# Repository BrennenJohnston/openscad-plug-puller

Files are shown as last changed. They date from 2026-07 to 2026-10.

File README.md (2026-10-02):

# openscad-plug-puller






## Overview

The **Plug Puller** is a handheld assistive device that helps you grip and
remove an electrical plug from a wall outlet with your whole hand instead of
a fingertip pinch: two finger holes take the pull, and the tool touches only
the plug's sides and back, never the outlet. It is for anyone with
arthritis, low grip strength, tremor, a small hand or one hand. It is a
parametric OpenSCAD model: measure a few things with a ruler (or match your
plug against a printed stencil card), type them into a form, export, print.

It comes as **two tools**, each in its own file:

- the **one-sided puller**,
  [`src/Plug_Puller_Parametric.scad`](src/Plug_Puller_Parametric.scad):
  a slab with a plug pocket, finger holes, a cord hook, and zip-tie /
  velcro attachment, for lamp plugs, standard 3-prong plugs and other
  plugs thinner than 24 mm;
- the **two-sided puller**,
  [`src/Plug_Puller_Two_Sided.scad`](src/Plug_Puller_Two_Sided.scad):
  two identical serrated plates that zip-tie face to face around a
  thick round plug, a USB-C tip or a charger plug.

Not sure which? Start with the one-sided puller. If your plug measures
24 mm thick or more, it shows a red tag:
`PLUG THICKER THAN 24MM - USE THE TWO-SIDED PULLER FILE`.

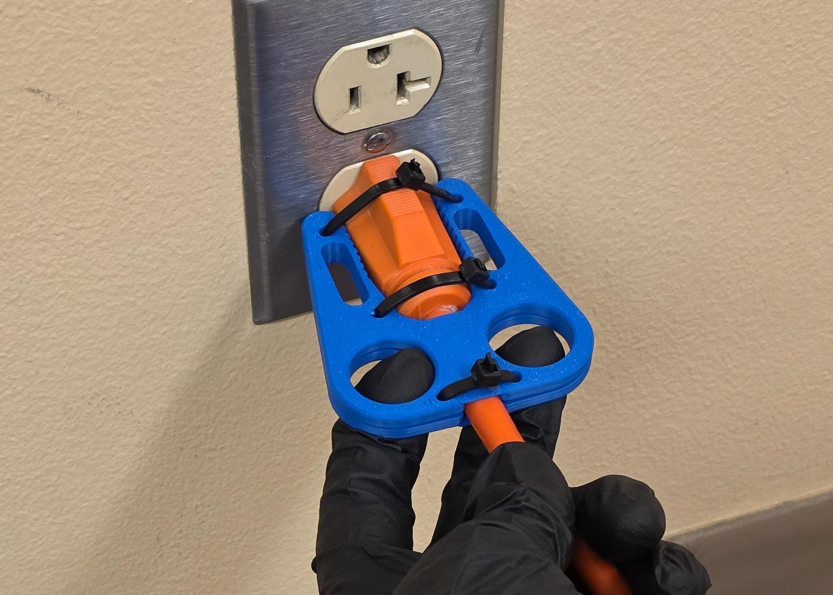
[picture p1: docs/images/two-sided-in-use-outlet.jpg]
A gloved hand pulling the two-sided puller and its orange extension-cord plug straight out of a wall outlet, two fingers through the holes.


> **Public preview** — one step from the **v1.0** public milestone. The
> geometry and guides are complete and print-tested, the shipped STLs
> are CI-validated against golden fixtures, and the model is
> customizable in the browser with nothing to install.

Each tool has two documents, as a page and as a printable PDF: a **quick
start** (get the file, measure, the four Customizer steps, print, assemble,
use) and a **full guide** (every dial, troubleshooting, the advanced dials).
One-sided puller: [quick start](docs/guides/one-sided/quick-start.md) and
[full guide](docs/guides/one-sided/full-guide.md). Two-sided puller:
[quick start](docs/guides/two-sided/quick-start.md) and
[full guide](docs/guides/two-sided/full-guide.md).

## How to obtain the device

### Customize in your browser

No install needed: the [OpenSCAD Assistive Forge](https://openscad-assistive-forge.pages.dev/),
our browser version of OpenSCAD built for keyboard and screen reader
use, opens the tool from one link, ready to customize, and offers to
keep a copy in your browser:
**[open the one-sided puller](https://openscad-assistive-forge.pages.dev/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)**
or
**[open the two-sided puller](https://openscad-assistive-forge.pages.dev/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)**.
The form shows the four steps' dials first. Each tool's quick start
covers it click by click under "Get the file", and its full guide adds
the notes for working in the browser. The links open the flattened
single-file builds, [`dist/Plug_Puller_SingleFile.scad`](dist/Plug_Puller_SingleFile.scad)
and [`dist/Plug_Puller_Two_Sided_SingleFile.scad`](dist/Plug_Puller_Two_Sided_SingleFile.scad),
as copied to the Forge's example branch.

### Customize on your computer

You don't need to know OpenSCAD (or any 3D modeling) to make a Plug
Puller that fits **your** plug and **your** hand.

1. Open the file for your tool in OpenSCAD (v2021.01 or later; recent
   builds with the Manifold backend render fastest):
   [`src/Plug_Puller_Parametric.scad`](src/Plug_Puller_Parametric.scad)
   for the one-sided puller, or
   [`src/Plug_Puller_Two_Sided.scad`](src/Plug_Puller_Two_Sided.scad)
   for the two-sided puller.
2. Open the **Customizer** panel (`View ▸ Hide Customizer` unchecked;
   older builds: `Window ▸ Customizer`).

   **One-sided puller:**
   - **Step 1 - Your Plug**: pick a `plug_preset` (or leave it on
     `Measure my plug` and type your plug measurements — see the
     [quick start](docs/guides/one-sided/quick-start.md)). Skip both to
     get the reference plug pocket. The preview shows a see-through
     plug built from your numbers. The measurements are named for where
     you take them: the **prong end** and the **cord end** (the pocket,
     notch, cord hook, and the plug side rail are built from them — no
     protractor needed).
   - **Step 2 - Size**: keep `Medium` for the reference tool, pick
     `Small` / `Large` (research-grounded ANSUR-II hand pairs), or pick
     `Measure my hand` and fill in the two hand measurements below the
     dropdown.
   - **Step 3 - Attachment**: `Zip ties + Velcro` (default), `Zip ties`,
     `Velcro strap`, or `None`; `velcro_style` is `Wing` (default) or
     `Classic slot`, with a `strap_width` setting.
   - **Step 4 - Cord Hook**: `hook_hand` = `Right` (the reference
     device) or `Left`; it picks the J-hook's chirality.

   **Two-sided puller:**
   - **Step 1 - Your Plug**: pick the `plug_preset`, or type four
     numbers (the plug's length, its width at the prong end and at the
     cord end, and the cord), then pick `Rounded sides` (a round plug,
     a USB-C or charger tip: the plates get a sloped cradle that
     centers it) or `Flat sides` (a boxy plug: the teeth bite along the
     whole side).
   - **Step 2 - Size**: `Small` / `Medium` / `Large`, or
     `Measure my hand` and your finger width.
   - **Step 3 - Attachment**: `Zip ties + Velcro strap` (default) or
     `Zip ties`. The zip ties are what hold the two plates together.
   - **Step 4 - Print Layout**: `Both plates` (default) puts both
     plates in one file; `One plate` exports a single plate.
3. Press **F6** to render, then `File ▸ Export ▸ STL` to save the
   print file. For the two-sided puller: print both plates, flip one
   over, zip-tie the pair face to face around the plug.

Everything below Step 4 in the Customizer is optional: the `Advanced -`
sections hold placement overrides (one-sided) and plate tuning
(two-sided), and the `(Custom size only)` sections of the one-sided
file only apply when `size = Custom`. `Custom` size unlocks every
individual slider of the one-sided puller for power users. What every
dial moves is drawn, before and after, in each tool's full guide
([one-sided](docs/guides/one-sided/full-guide.md),
[two-sided](docs/guides/two-sided/full-guide.md); printable as
[`docs/Plug_Puller_One_Sided_Full_Guide.pdf`](docs/Plug_Puller_One_Sided_Full_Guide.pdf)
and [`docs/Plug_Puller_Two_Sided_Full_Guide.pdf`](docs/Plug_Puller_Two_Sided_Full_Guide.pdf)),
which also explains how the advanced dials work together.

Prefer a single file (e.g. for the MakerWorld customizer or offline
sharing)? Use [`dist/Plug_Puller_SingleFile.scad`](dist/Plug_Puller_SingleFile.scad)
(one-sided) or
[`dist/Plug_Puller_Two_Sided_SingleFile.scad`](dist/Plug_Puller_Two_Sided_SingleFile.scad)
(two-sided) — each model flattened into one file.

### Download a ready-to-print STL

No OpenSCAD needed — the [`stl/`](stl) folder ships a pre-rendered copy of
every preset at every hand size, named so you can grab yours without opening
the Customizer. [`stl/README.md`](stl/README.md) is a one-line index of the
whole library; the two groups are:

**Plug pullers** — [`stl/Plug-Puller/`](stl/Plug-Puller):

Pick your plug family, then your hand size (`Small` / `Medium` / `Large` —
Medium is the reference device, so start there; Small ≈ 5th-percentile female
hand, Large ≈ 95th-percentile male hand).

| Plug family | Files (`_Small` / `_Medium` / `_Large`) | Tool |
| --- | --- | ---- |
| Flat 2-prong lamp — NEMA 1-15 | `Plug-Puller_Flat-2-Prong-Lamp-NEMA-1-15_*.stl` | one-sided puller (one part) |
| Standard 3-prong — NEMA 5-15 | `Plug-Puller_Standard-3-Prong-NEMA-5-15_*.stl` | one-sided puller (one part) |
| Wide 2-prong appliance — NEMA 1-15 | `Plug-Puller_Wide-2-Prong-Appliance_*.stl` | one-sided puller (one part) |
| Heavy-duty extension cord — NEMA 5-15 | `Plug-Puller_Two-Sided_Round-Extension-Cord-NEMA-5-15_*.stl` | two-sided puller (both plates) |
| USB-C laptop tip | `Plug-Puller_Two-Sided_USB-C-Laptop-Tip_*.stl` | two-sided puller (both plates) |
| Flat 2-prong lamp — NEMA 1-15 | `Plug-Puller_Two-Sided_Flat-2-Prong-Lamp-NEMA-1-15_*.stl` | two-sided puller (both plates) |
| Standard 3-prong — NEMA 5-15 | `Plug-Puller_Two-Sided_Standard-3-Prong-NEMA-5-15_*.stl` | two-sided puller (both plates) |

Each two-sided file holds both plates: flip one after printing, then zip-tie
the pair face to face around the plug.

**Measuring stencil** — [`stl/Measuring-Stencil/`](stl/Measuring-Stencil):

Thin measuring cards that answer the fit worksheet without a caliper. Print the
full packed set (`..._All-Cards.stl`) or just the one card you need, in either
label mode:

- **Visual** ([`Measuring-Stencil/Visual/`](stl/Measuring-Stencil/Visual)) — debossed printed labels.
- **Tactile** ([`Measuring-Stencil/Tactile/`](stl/Measuring-Stencil/Tactile)) — raised ADA-size characters plus a fold-flat Grade 2 braille title flap on every card (snap off the support fins, fold each flap back until flat — see "Match a card instead of measuring" in either [quick start](docs/guides/one-sided/quick-start.md#match-a-card-instead-of-measuring)).

| Card | Purpose |
| ---- | --- |
| `All-Cards` | the full packed set — every card on one plate |
| `P1_Lamp-Plug-Gauge` / `P2_Standard-3-Prong-Gauge` / `P3_Heavy-Duty-Cord-Gauge` / `P4_Wide-2-Prong-Appliance-Gauge` | plug-preset silhouettes |
| `R1_Ruler-100mm` | a tactile 100 mm ruler |
| `C1_Cord-Gauge` | open-slot cord gauge that slides onto an installed cord |
| `F1_Finger-Sizing-15-25mm` / `F2_Finger-Sizing-26-32mm` | all 18 finger-sizing holes |

The whole library is regenerated from source by
[`scripts/build_release_stls.py`](scripts/build_release_stls.py).

Not sure which size? Print a **1:1 paper outline sheet** of any
preset-and-size combination first and test it against your real plug and
hand: every sheet is in one printable PDF,
[`docs/Plug_Puller_Outline_Sheets.pdf`](docs/Plug_Puller_Outline_Sheets.pdf),
and each full guide's "Try it on paper first" section lists its tool's
sheets. For a tool matched to *your* plug and hand, spend five minutes
with the quick start's measuring section and the Customizer instead.

## Build instructions

Each tool's **quick start** carries the whole path, in order: get the
file, measure your plug and your hand (or match a stencil card), fill in
the four Customizer steps, render and print, assemble, use. It is a page
([one-sided](docs/guides/one-sided/quick-start.md),
[two-sided](docs/guides/two-sided/quick-start.md)) and a printable PDF
whose last pages are the measuring form and the 1:1 paper stencil sheets
([`docs/Plug_Puller_One_Sided_Quick_Start.pdf`](docs/Plug_Puller_One_Sided_Quick_Start.pdf),
[`docs/Plug_Puller_Two_Sided_Quick_Start.pdf`](docs/Plug_Puller_Two_Sided_Quick_Start.pdf)).
If the print is snug or loose, the tool's **full guide** says which one
number to nudge and decodes every red warning tag
([one-sided](docs/guides/one-sided/full-guide.md#if-the-print-does-not-fit),
[two-sided](docs/guides/two-sided/full-guide.md#if-the-print-does-not-fit)).
What to buy is in the **[bill of materials](docs/guides/bom.md)**.

### 3D printing tips

- **Orientation:** print with `Z = 0` flat on the print bed (the flat
  bottom face) so the plug pocket faces upward. The pocket floors are
  flat terraces — no supports required.
- **Two-sided puller:** print the file as exported — both plates lie
  flat on their outer faces, no supports. After printing, flip one
  plate over so the two plates meet face to face around the plug.
- **Layer height:** 0.2 mm gives a clean finish on the pocket walls;
  0.16 mm sharpens the rim fillets on the 6.35 mm slab.
- **Infill:** 25–35 % cubic or gyroid is plenty for hand strength. The
  pull cord, not the slab, takes most of the load.
- **Walls / perimeters:** 3–4 walls. The zip-tie holes and optional
  velcro slots cut close to the pocket, so thin walls make those
  regions fragile.
- **Material:** PETG is the recommended default — it tolerates the
  cord-tension fatigue cycle better than PLA and resists outlet heat
  near a misbehaving plug. ABS / ASA work too. Avoid soft TPU; the
  device needs to stay rigid for the hook to grip the cord.
- **Quality slider:** the default `quality = 64` is already
  print-ready. Drop to `32` for fast previews; push to `96` or `128`
  only if you specifically need crisp curvature on a very large export.

## How to use it

Each quick start's "Use it" section covers it: seat the one-sided puller
on the plugged-in plug, hook the cord, put two fingers in the holes and
pull straight out; the two-sided puller stays on the plug and pulls the
same way. The safety rules follow it (nothing between the plug face and
the outlet; pull straight, never lever), and the full guide adds the care
of the tool. If red text appears beside the part in the preview, the full
guide's "Red warning tags" section decodes it.

## How to improve this device

The model is built to be changed and checked. Its data files, its tests and
its scripts are all in the repository:

- **The Customizer schemas:** [`parameter_mapping.json`](parameter_mapping.json)
  (one-sided, 79 parameters) and
  [`parameter_mapping_two_sided.json`](parameter_mapping_two_sided.json)
  (two-sided, 39 parameters) list every name, type, range, step and default;
  [`dial_catalog.json`](dial_catalog.json) holds every dial's title, sentence
  and diagram settings, and the diagrams themselves are under
  [`docs/dials/`](docs/dials/README.md).
- **The engineering deep-dive:**
  [`docs/Plug_Puller_Reference.md`](docs/Plug_Puller_Reference.md) (both
  tools, coordinate frames, the plug side rail, the two-sided plate geometry,
  CSG order, sizes, the derivation layer, render modes, validation warnings)
  and the [Design rationale](docs/guides/design-rationale.md) (why each
  default is what it is).
- **The scripts:** [`scripts/README.md`](scripts/README.md) lists every
  build and check script (the release library, the outline sheets, the PDFs,
  the dial diagrams, the docs gate).
- **The tests:** `python -m pytest -m "not requires_openscad" -p no:cacheprovider`
  runs the quick lane; the render lane (`-m requires_openscad`) needs the
  OpenSCAD 2026.01.03 nightly; CI runs both.
- **Publishing to MakerWorld:** its Parametric Model Maker runs OpenSCAD
  files directly. Upload the single-file build of each tool
  ([`dist/Plug_Puller_SingleFile.scad`](dist/Plug_Puller_SingleFile.scad)
  and [`dist/Plug_Puller_Two_Sided_SingleFile.scad`](dist/Plug_Puller_Two_Sided_SingleFile.scad));
  the multi-file `src/` tree will not work there because `include <>` files
  are not uploaded alongside it. MakerWorld auto-detects a `.scad` upload
  and adds the **Customize** button; the parameter form mirrors the
  Customizer sections. Test the customizer behavior first via
  **Creator Portal → Open SCAD File** before publishing. The listing text
  is in [`docs/makerworld-listing.md`](docs/makerworld-listing.md), and the
  user guide that goes with it is
  [`docs/MAKERWORLD_QUICK_START.md`](docs/MAKERWORLD_QUICK_START.md); both
  follow the shared
  [Accessible MakerWorld Documentation Standard](https://github.com/BrennenJohnston/accessible-makerworld-doc-standard/blob/main/ACCESSIBLE_MAKERWORLD_DOC_STANDARD.md).
  The licensing decision recorded in the listing is made: downloads from
  MakerWorld use CC BY-NC-SA 4.0, the listing license closest to this
  repo's PolyForm NC 1.0.0, which still covers the repository itself. The
  maintainer runs the smoke test and publishes from their own MakerWorld
  account.

### Features

Both tools:

- **Two tools, two files.** The one-sided puller and the two-sided puller
  share one size table (`src/fit_sizes.scad`); a plug 24 mm thick or more
  gets a red tag in the one-sided file that points to the two-sided file.
- **Measurement-first Customizer.** Plug measurements are Step 1 and always
  active, named for where you take them: the **prong end** and the **cord
  end**; sizes and attachment are one dropdown each.
- **Plug quick-select.** `plug_preset` prefills the measured US plug
  families: the lamp, standard and wide appliance plugs in the one-sided
  file; the round extension cord, the USB-C laptop tip, the lamp and the
  standard plug in the two-sided file. `Measure my plug` keeps the sliders
  authoritative.
- **See-through plug.** The preview draws a translucent plug built from your
  numbers in the pocket or between the plates (`show_plug_preview`, on by
  default), so you can check the fit before printing; it is never exported.
- **In-model validation.** A red warning tag is printed flat on the bed next
  to the part when a check trips (one-sided W-1…W-20; two-sided WC-1…WC-13),
  including hole-collision checks; the messages name the *measurement* to
  fix; a preview-only green tag confirms your numbers were applied.
- **Try-before-you-print previews.** [1:1 dimensioned outline sheets](docs/guides/one-sided/full-guide.md#try-it-on-paper-first)
  for every preset-and-size combination (cut out, hold against the plug, try
  the finger holes) plus the printable [measuring stencil](Measuring_Stencil.scad)
  with plug silhouettes, ruler, cord gauge, and finger holes.

The one-sided puller:

- **Plug side rail.** The pocket walls, zip stations, and velcro slot follow
  one rail down the plug's side; the rail's taper angle is derived from the
  two Step 1 width stations over the plug length, so one taper moves
  everything coherently.
- **Organic body.** A rounded organic silhouette reproduced by a fitted
  octagon + side rounding; crisp plug end, blob-rounded cord end, wider
  shoulder ears.
- **Dome plug pocket.** A two-level pocket: a plug-shaped recess plus a
  deeper circular seat centered on the top edge; the two floor heights are
  directly settable in Custom.
- **Finger holes.** A mirrored pair, Ø 25.4 mm at Medium, quarter-round rim
  fillets on both faces.
- **Cord J-hook.** A chiral J-hook cord catch: an offset stem, a catch lip
  that reaches past the stem, and a tip that drops below Y = 0 so a hooked
  cord cannot back out (`hook_hand` mirrors left/right).
- **Plug wall notch.** A rounded-corner notch that straddles the outlet wall
  plate; its depth follows the wall-plate style dropdown.
- **Zip-tie holes.** A 2×2 grid of Ø 5.08 mm holes, with a top-face
  countersink flare on the exposed lower row.
- **Wing velcro slots.** The default `Wing` style: curved triangular cutouts
  filling the dead space between finger hole, pocket, side edge, and zip
  holes; `strap_width` is checked against them; a `Classic slot` fallback
  keeps rectangular slots.
- **Round-plug retention.** Smooth-sided round plugs are held by the pocket
  walls plus a zip tie cinched through the existing zip-tie hole grid; fat
  round plugs are gripped between the two-sided puller's serrated plates.
- **Auto-fit.** Every feature is bounds-clamped against the body envelope so
  measured sizes never self-intersect; in Custom mode every clamp is
  reported in the console (`(clamped from …)`) with a preview HUD notice.
- **Render mode dispatch.** The file renders the full tool, body only,
  isolated cutouts, or a 2D cutout overlay.

The two-sided puller:

- **Two identical plates.** Serrated plates that zip-tie face to face around
  the plug; `print_layout = Both plates` (the default) puts both side by
  side in one file — flip one after printing.
- **Rounded or flat sides.** `plug_sides`: `Rounded sides` gives each plate
  a sloped cradle (`plate_cradle_depth`, 2.5 mm per side, with
  `plate_grip_clearance` 0.5 mm where the plates meet) that centers a round
  plug, a USB-C or charger tip; `Flat sides` keeps the edge straight so the
  teeth bite along a boxy plug's whole side.
- **Serrated grip.** Teeth along both arms follow the cradle's slope;
  `plate_grip_bite` tunes the bite for `Flat sides` and the plug presets.
- **Cord channel.** A channel between the finger holes carries the cord out
  of the pair.
- **Finger holes.** Your finger width plus `plate_finger_fit` (1 mm):
  Ø 17.5 / 21 / 24 mm at Small / Medium / Large.
- **Zip-tie stations and strap slots.** Zip-tie holes along both arms, and a
  velcro strap slot in each arm when the plug is long enough (on a short
  plug it is left out, with an orange preview note).
- **Plate dials.** `Advanced - Two-Sided Puller`: 26 `plate_*` dials, led by
  `plate_wall_boost`, which thickens every wall at once.

### Sizes

Both files read the same Small / Medium / Large finger widths from
[`src/fit_sizes.scad`](src/fit_sizes.scad). In the one-sided puller,
all non-Custom sizes route through the measurement derivation layer
([`src/fit_measured.scad`](src/fit_measured.scad)): the plug
measurements (or a `plug_preset`) drive the pocket / notch / J-hook, and
the size picks the hand pair that drives the grip and body envelope. The
hand pairs are research-grounded (ANSUR II 2012 hand breadth + Rogers 2008
PIP-joint breadth): Small ≈ 5th %ile female, Large ≈ 95th %ile male.

| Size | Hand pair (finger / hand) | Body | Notes |
| ---- | --- | ---- | ----- |
| `Small` | 16.5 / 72 mm | ≈ 60 × 65 × 5.4 mm | scaled-down grip |
| `Medium` | 20 / 85 mm | 81.55 × 65.5 × 6.35 mm (octagon) | **= the reference device** |
| `Large` | 23 / 96 mm | ≈ 78 × 66 × 7.2 mm | scaled-up grip |
| `Measure my hand` | your two measurements | derived | defaults reproduce Medium exactly |
| `Custom` | — | sliders | measurements ignored; every slider unlocked |

The two-sided puller uses the finger width only: its finger holes are
Ø 17.5 / 21 / 24 mm at Small / Medium / Large, `Measure my hand` asks
for your finger width alone, and there is no `Custom` size.

### Saved Customizer parameter sets

[`presets/Plug_Puller_Parametric.json`](presets/Plug_Puller_Parametric.json)
ships example parameter sets for the one-sided puller (snapshots of
Customizer values):

| Name in JSON | Loads as | Notes |
| --- | --- | ----- |
| `Medium (v6 reference)` | `Medium` | the one-sided reference device, zip ties + wing velcro |
| `Flat 2-prong lamp plug (NEMA 1-15)` | `plug_preset` | 37 mm long, width 25 → 11.2, thickness 18.6 → 8.6 (prong end → cord end), 3.6 mm cord |
| `Standard 3-prong plug (NEMA 5-15)` | `plug_preset` | 46.2 mm long, width 26.6 → 13.4, thickness 18.9 → 15, 7 mm cord |
| `Wide 2-prong appliance plug - NEMA 1-15` | `plug_preset` | 38 mm long, 34 wide and 16 thick at both ends, 5 mm cord |
| `Small hands` / `Large hands` | `Small` / `Large` | ANSUR-II grip scaling |
| `Measure my plug + hand (US vacuum plug)` | `Measure my hand` | the same plug typed by hand, Decora plate, 22 / 88 mm hand |
| `Left-handed + classic velcro slots` | `Medium` | `hook_hand = Left`, `velcro_style = Classic slot` |

[`presets/Plug_Puller_Two_Sided.json`](presets/Plug_Puller_Two_Sided.json)
ships sets for the two-sided puller:

| Name in JSON | Loads as | Notes |
| --- | --- | ----- |
| `Round extension cord - NEMA 5-15` | `plug_preset` | the heavy-duty extension-cord plug, Medium, zip ties + velcro strap |
| `USB-C laptop plug - measured` | `Measure my plug` | 23 mm long, 13 mm wide at both ends, 7 mm cord, `Rounded sides`, zip ties only |
| `USB-C laptop tip`, `Flat 2-prong lamp plug - NEMA 1-15`, `Standard 3-prong plug - NEMA 5-15` | `plug_preset` | the three presets added after 0.12, Medium |

### Auto-fit and `custom_enable_auto_fit`

Auto-fit clamps geometry into safe ranges (always on for the measured
sizes, toggleable in Custom). When enabled, feature placement is
re-derived from the current body envelope. Disable it only when you
specifically need to push features outside the envelope; the
**in-model validation warnings** (red text past the plug end) will tell
you which checks failed.

### Render modes

The hidden `render_mode` parameter controls which subset of geometry is
built. In the one-sided file:

| Mode | What it renders |
| ---- | --- |
| `Full` | The tool: pocketed body + cutouts + warnings |
| `Body Only` | Pocketed body + cutouts |
| `Body No Cutouts` | Solid body, no pocket, no holes (debug view) |
| `Only Finger Holes` / `Only T Hook` / `Only Plug Wall Notch` / `Only Zip Tie Holes` / `Only Velcro Strap Holes` | Plain body + a single feature cutout |
| `Cutouts Only 2D` | 2D overlay of every cutout + pocket profile (debug) |

In the two-sided file, `Full` builds what Step 4's `print_layout` picks
(both plates side by side, or one plate) and `One plate` always builds
a single plate.

### Troubleshooting

| Symptom | Likely cause | Where to look |
| --- | --- | --- |
| Red warning tag lies flat on the bed past the end of the model | One of the in-model validation checks tripped | The tag names the check and the measurement to fix; see Red warning tags in the [one-sided](docs/guides/one-sided/full-guide.md#red-warning-tags) or [two-sided](docs/guides/two-sided/full-guide.md#red-warning-tags) full guide |
| Red tag `PLUG THICKER THAN 24MM - USE THE TWO-SIDED PULLER FILE` | The plug is too thick for the one-sided puller's pocket | Open [`src/Plug_Puller_Two_Sided.scad`](src/Plug_Puller_Two_Sided.scad) and fill in its Step 1 |
| Orange `STRAP SLOT LEFT OUT - PLUG TOO SHORT FOR ONE` in the two-sided preview | The plug is too short for a velcro strap slot in the arms; the zip ties still hold the plates | Nothing to fix; or pick `Zip ties` in Step 3 |
| Green `Medium: …` (or `MEASURED: …`) tag in the preview | Not a problem: preview-only confirmation that your measurements were applied; never in the exported STL | — |
| Orange `CUSTOM SLIDERS IGNORED - SET SIZE = CUSTOM` tag in the preview | A `custom_*` slider was moved while a non-Custom size is active; those sliders only apply when `size = Custom` | The `size` dropdown (Step 2) |
| Typed measurements but the model doesn't change | `size` is set to `Custom` — measurements are ignored there. Pick any other size | The `size` dropdown (Step 2) |
| Sliders ignored | The measured sizes override the custom sliders via the derivation layer (the preview shows the orange HUD tag). Switch `size` to `Custom` | [`src/presets.scad`](src/presets.scad) |
| Smooth round plug slips out of the pocket | Round cord ends have no shoulders for the notch to catch | Thread a zip tie down one zip-tie hole, around the plug barrel, up the opposite hole, and cinch it |
| Hand sliders do nothing | `measure_finger_width` / `measure_hand_width` apply only when `size = Measure my hand` | Step 2 of the Customizer |
| Customizer never shows a slider you expected | Either the parameter lives under `/* [Hidden] */` (e.g. `render_mode`), or you are not in `Custom` size | [`parameter_mapping.json`](parameter_mapping.json) lists every user-facing parameter |

Every warning is also echoed to the console, and in the measured sizes the
message names the *measurement* to fix. The orange `CUSTOM SLIDERS IGNORED`
notice lists each ignored slider by name in the console.

## Files

### Documentation

Organized by audience — start in the row that matches you.

For makers and users:

| Document | Description |
| --- | --- |
| [`docs/guides/one-sided/quick-start.md`](docs/guides/one-sided/quick-start.md) | **Start here for a plug up to 24 mm thick.** Measure or match a card, the four steps, print, assemble, use |
| [`docs/guides/one-sided/full-guide.md`](docs/guides/one-sided/full-guide.md) | Everything about the one-sided puller: every dial with a picture, fit troubleshooting, every warning, the advanced dials |
| [`docs/guides/two-sided/quick-start.md`](docs/guides/two-sided/quick-start.md) | **Start here for a thicker plug, a USB-C tip or a round cord plug.** The same path for the two-sided puller |
| [`docs/guides/two-sided/full-guide.md`](docs/guides/two-sided/full-guide.md) | Everything about the two-sided puller |
| [`docs/Plug_Puller_One_Sided_Quick_Start.pdf`](docs/Plug_Puller_One_Sided_Quick_Start.pdf) | The one-sided quick start to print, with the measuring form and the paper stencil sheets at 1:1 as its last pages |
| [`docs/Plug_Puller_One_Sided_Full_Guide.pdf`](docs/Plug_Puller_One_Sided_Full_Guide.pdf) | The one-sided full guide to print |
| [`docs/Plug_Puller_Two_Sided_Quick_Start.pdf`](docs/Plug_Puller_Two_Sided_Quick_Start.pdf) | The two-sided quick start to print, with the form and the stencil sheet |
| [`docs/Plug_Puller_Two_Sided_Full_Guide.pdf`](docs/Plug_Puller_Two_Sided_Full_Guide.pdf) | The two-sided full guide to print |
| [`docs/guides/bom.md`](docs/guides/bom.md) | Zip ties, the strap, filament per tool |
| [`docs/guides/design-rationale.md`](docs/guides/design-rationale.md) | Why each default is what it is, with its number and its source |
| [`docs/guides/stencil-sheet.svg`](docs/guides/stencil-sheet.svg) | The 1:1 paper stencil sheet on its own: calibration square, P1–P3 plug silhouettes, mm ruler, finger circles |
| [`docs/guides/stencil-sheet-2.svg`](docs/guides/stencil-sheet-2.svg) | The second stencil page: the P4 wide appliance plug silhouette |
| [`docs/guides/one-sided/measuring-form.svg`](docs/guides/one-sided/measuring-form.svg) | The one-sided measuring form sheet on its own; its text is in the quick start |
| [`docs/guides/two-sided/measuring-form.svg`](docs/guides/two-sided/measuring-form.svg) | The two-sided measuring form sheet on its own |
| [`docs/Plug_Puller_Outline_Sheets.pdf`](docs/Plug_Puller_Outline_Sheets.pdf) | Every 1:1 outline sheet in one printable PDF with a cover index |
| [`docs/guides/source/`](docs/guides/source) | The hand-written text of the four guides, one topic per file; edit here, then rebuild |

For power users (the Advanced and Custom tiers):

| Document | Description |
| --- | --- |
| [Advanced settings, one-sided](docs/guides/one-sided/full-guide.md#advanced-settings) and [two-sided](docs/guides/two-sided/full-guide.md#advanced-settings) | The advanced dials explained, Custom size (one-sided), saved settings, the command line; render modes and console diagnostics are in the reference |
| [`parameter_mapping.json`](parameter_mapping.json) | Machine-readable Customizer schema of the one-sided puller (79 parameters) |
| [`parameter_mapping_two_sided.json`](parameter_mapping_two_sided.json) | The same for the two-sided puller (39 parameters) |
| [`dial_catalog.json`](dial_catalog.json) | Every dial's title, sentence and diagram settings; the source of `docs/dials/` and the dial reference |

For contributors and engineers:

| Document | Description |
| --- | --- |
| [`docs/Plug_Puller_Reference.md`](docs/Plug_Puller_Reference.md) | Exhaustive reference: both tools, coordinate frames, the plug side rail, the plate geometry, CSG order, sizes, derivation layer, render modes, warnings |
| [`docs/makerworld-listing.md`](docs/makerworld-listing.md) | The MakerWorld listing text |
| [`docs/MAKERWORLD_QUICK_START.md`](docs/MAKERWORLD_QUICK_START.md) | The user guide that goes with the listing |
| [`docs/guides/describing-pictures.md`](docs/guides/describing-pictures.md) | How every picture's alt text and long description are written, with the sources |
| [`scripts/README.md`](scripts/README.md) | Every build and check script |
| [`CHANGELOG.md`](CHANGELOG.md) | Keep-a-Changelog release history |
| [`okh.yml`](okh.yml) | The Open Know-How manifest |

### Design files

- [`src/Plug_Puller_Parametric.scad`](src/Plug_Puller_Parametric.scad): the one-sided puller, open this in OpenSCAD.
- [`src/Plug_Puller_Two_Sided.scad`](src/Plug_Puller_Two_Sided.scad): the two-sided puller, open this in OpenSCAD.
- [`src/fit_sizes.scad`](src/fit_sizes.scad), [`src/presets.scad`](src/presets.scad), [`src/fit_measured.scad`](src/fit_measured.scad): the shared size table, the Medium reference table and routing, and the measurement-to-parameter derivations (one-sided).
- [`Measuring_Stencil.scad`](Measuring_Stencil.scad): the standalone printable measuring stencil.

### Build files

- [`stl/`](stl): the ready-to-print library (see [`stl/README.md`](stl/README.md)): `Plug-Puller/` holds 21 tools (the presets of both files at three hand sizes; both plates per two-sided file), `Measuring-Stencil/` the sizing cards in Visual and Tactile label modes.
- [`dist/`](dist): the single-file builds of both pullers for MakerWorld and the web customizer.
- [`presets/`](presets): example saved Customizer parameter sets for both files.
- [`docs/dials/`](docs/dials/README.md): a diagram per dial, and their index.

Repository layout:

```
openscad-plug-puller/
  Measuring_Stencil.scad           # standalone printable measuring stencil
  okh.yml                          # Open Know-How manifest
  src/
    Plug_Puller_Parametric.scad    # the one-sided puller — open this in OpenSCAD
    Plug_Puller_Two_Sided.scad     # the two-sided puller — open this in OpenSCAD
    fit_sizes.scad                 # Small / Medium / Large size table, shared by both files
    presets.scad                   # PRESET_MEDIUM reference table + routing (one-sided)
    fit_measured.scad              # measurement -> parameter derivations (one-sided)
  dist/
    Plug_Puller_SingleFile.scad    # one-sided single-file build (MakerWorld / web)
    Plug_Puller_Two_Sided_SingleFile.scad  # two-sided single-file build (MakerWorld / web)
  presets/
    Plug_Puller_Parametric.json    # example saved Customizer parameter sets (one-sided)
    Plug_Puller_Two_Sided.json     # example saved Customizer parameter sets (two-sided)
  stl/                             # ready-to-print library (see stl/README.md)
    Plug-Puller/                   # 21 tools: the presets of both files at three sizes
    Measuring-Stencil/             # sizing cards, in Visual/ and Tactile/ label modes
  docs/
    Plug_Puller_Reference.md       # exhaustive engineering reference
    Plug_Puller_One_Sided_Quick_Start.pdf  # the one-sided quick start, with the form and the stencil sheets
    Plug_Puller_One_Sided_Full_Guide.pdf   # the one-sided full guide
    Plug_Puller_Two_Sided_Quick_Start.pdf  # the two-sided quick start
    Plug_Puller_Two_Sided_Full_Guide.pdf   # the two-sided full guide
    Plug_Puller_Outline_Sheets.pdf # every 1:1 outline sheet as one printable PDF
    guides/                        # the BOM, the rationale, the paper stencil sheets, how the pictures are described
      source/                      # the hand-written text of the guides, one topic per file
      one-sided/                   # the one-sided quick start and full guide pages, and its form sheet
      two-sided/                   # the two-sided quick start and full guide pages, and its form sheet
      outline-sheets/              # printable 1:1 outline sheets (one per preset-and-size combination)
    dials/                         # a diagram per dial, their index and README
    images/                        # guide photos and model preview renders
  dial_catalog.json                # every dial's title, sentence and diagram settings
  parameter_mapping.json           # one-sided Customizer schema (79 parameters)
  parameter_mapping_two_sided.json # two-sided Customizer schema (39 parameters)
  CHANGELOG.md
  LICENSE                          # PolyForm Noncommercial 1.0.0
```

## License

[PolyForm Noncommercial 1.0.0](LICENSE). Personal, hobby, educational,
research, and other noncommercial use is permitted. Contact the
maintainer for commercial use.

## Attribution

- The repository structure and the documentation set follow the
  [OpenAT Template](https://github.com/makersmakingchange/OpenAT-Template)
  by Makers Making Change.
- [`braille-stl-generator-openscad`](https://github.com/BrennenJohnston/braille-stl-generator-openscad) — sibling parametric OpenSCAD project; the pipeline conventions (presets.scad, in-model warnings) used here were adapted from it.
- The hand sizes come from the ANSUR II (2012) hand breadth survey and
  Rogers (2008) knuckle breadth; the documentation is written to the
  [Accessible MakerWorld Documentation Standard](https://github.com/BrennenJohnston/accessible-makerworld-doc-standard/blob/main/ACCESSIBLE_MAKERWORLD_DOC_STANDARD.md).

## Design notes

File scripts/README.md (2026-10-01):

# scripts/

Utility scripts used to build and validate the Plug Puller model's committed artifacts. All paths are relative to the repo root; run them from there, e.g. `python scripts/build_flattened.py`.

## Contents

| Script | Purpose |
|---|---|
| `build_flattened.py` | Deterministically inline each model's include tree into its single-file artifact for web customizers (the OpenSCAD Assistive Forge's example branch, MakerWorld PMM, openscad-playground `?src=` loading): `dist/Plug_Puller_SingleFile.scad` from `src/Plug_Puller_Parametric.scad` (inlines `src/fit_sizes.scad`, `src/fit_measured.scad` and `src/presets.scad`) and `dist/Plug_Puller_Two_Sided_SingleFile.scad` from `src/Plug_Puller_Two_Sided.scad` (inlines `src/fit_sizes.scad`); `--check` verifies both are fresh (CI does this on every run). |
| `regenerate_fixtures.py` | Re-render every golden STL under `tests/fixtures/<name>/reference.stl` from its `params.json`, and refresh the matching `metadata.json` with OpenSCAD version + trimesh measurements. Run after any intentional SCAD change so the mesh-comparison tests in `tests/test_render_modes.py` keep validating actual deltas, not stale references. Writes binary STLs, and leaves a fixture alone, `metadata.json` included, when its shape did not change; `--force` rewrites every one. |
| `build_release_stls.py` | Render the committed ready-to-print library under `stl/`: 21 plug tools in `stl/Plug-Puller/` (9 one-sided pullers for the lamp, standard and wide appliance plug presets × 3 hand sizes, and 12 two-sided pullers for the heavy-duty cord, USB-C tip, lamp and standard presets × 3 hand sizes, both plates in each file) + 18 measuring-stencil cards (Visual/Tactile full sets and individual cards, in `stl/Measuring-Stencil/`). Each output is a binary STL, without the zero-area triangles that binary's 32-bit coordinates leave where OpenSCAD's shortest edges collapse, and is watertight-checked; a file whose shape did not change is left alone, and `--force` rewrites every file. Run after any intentional model change and commit the refreshed `stl/`; `tests/test_shipped_stls.py` reuses this script's job catalog to guard the shipped files. Use `--only plug-puller` / `--only stencil` to rebuild one group. |
| `generate_outline_sheets.py` | Generate the try-before-you-print outline sheets (`docs/guides/outline-sheets/`, 21 SVGs): render each quick-select combination (the lamp, standard and wide appliance plug presets × 3 sizes for the one-sided puller, plus one two-sided puller plate for the heavy-duty cord, USB-C tip, lamp and standard presets × 3 sizes) via the OpenSCAD CLI, extract the true 1:1 silhouette / through-holes / pocket opening with trimesh + shapely, compute the labeled dimensions from `tests/fit_formulas.py`, and compose A4/Letter SVG sheets with CAD dimension lines and a calibration square. Asserts dimension parity between the mesh, the formulas, and the sheet before writing. Re-run after any geometry or preset change. |
| `build_outline_sheets_pdf.py` | Bundle the 21 outline-sheet SVGs into the printable `docs/Plug_Puller_Outline_Sheets.pdf` (cover/index page + one sheet per page) via headless Edge/Chrome — the same Skia print pipeline as the other PDF guides. The `@page` size equals the SVG page (210 × 279 mm) so the sheets keep their exact 1:1 scale; the script verifies the page count and every page's MediaBox after printing, then the document title and a bookmark on every page (hidden headings name each plug and each hand size; Chromium places a bookmark only where its heading is painted). Run after `generate_outline_sheets.py`. |
| `generate_stencil_sheet.py` | Emit `docs/guides/stencil-sheet.svg`, the 1:1 paper alternative to the 3D-printable `Measuring_Stencil.scad`: one 210 × 279 mm page with the 50 mm calibration square, the P1–P3 plug silhouettes, a 100 mm ruler, and the 18 finger circles. Its `PLUG_PRESET_DIMS` constant is drift-tested against both SCAD files by `tests/test_stencil_data.py`. Re-run after any preset-dimension change. |
| `generate_measuring_form.py` | Draw the two measuring form sheets, `docs/guides/one-sided/measuring-form.svg` and `docs/guides/two-sided/measuring-form.svg` (210 × 279 mm): one row per Step dial in Customizer order from the parameter mappings (the name, the plain title, the default and a blank, or tick boxes for a dropdown), a schematic plug drawn from the tool's defaults at 1.5:1 with a knuckle bar and a strap bar at 1:1, and a straight numbered leader from every measured row to a red dimension line on the feature its catalog `measure.anchor` names. `build_sheet()` also returns the form's text (the rows as a table, then what the sheet shows), which `build_dial_reference.py` places in each tool's quick start and full guide. The script fails if two leaders cross or a leader runs through a drawing. |
| `generate_dial_diagrams.py` | Draw one diagram per Customizer dial under `docs/dials/` from `dial_catalog.json` (reads the two parameter mappings for the defaults): each row is rendered twice via the OpenSCAD CLI (the defaults plus the row's context, then the dial at its `after` value), the top view is extracted with the outline-sheet helpers (shadow silhouette, through-holes and pocket recess for the one-sided puller; the contact-face section for a two-sided plate), and the symmetric difference becomes the red dashed trace over the black default outline and the teal plug. Writes `docs/dials/one-sided/<name>.svg`, `docs/dials/two-sided/<name>.svg` (1 unit = 1 mm, with `<title>` / `<desc>` text equivalents; "no shape" rows get a 120 × 40 mm card) and `docs/dials/dial_diagrams_index.json` (values, region count, changed area, warning tags and the named features the trace touches, per dial), then `docs/dials/README.md` (every diagram inline with its sentence as alt text; `--readme` rewrites it alone from the index). Renders are cached under `tmp_renders/dial_diagrams/` (keyed by the parameter set and the SCAD sources; `--force` re-renders). `--file`, `--only NAME` and `--views {top,none,section,all}` limit a run. A full forced run of all 118 rows is 214 renders, about 6 minutes on the reference PC (measured 2026-09-26: the 89 top rows 4 min 43 s with 148 s inside OpenSCAD, the 18 section rows 39 s); a cached run of every row about 3 minutes. |
| `build_dial_reference.py` | Build one tool's two guide documents (`--tool one-sided` or `--tool two-sided`; `--document quick-start` or `full-guide`, default both) from `dial_catalog.json` (its `measure` rows too), both parameter mappings, `docs/dials/dial_diagrams_index.json`, `docs/dials/storyboards_index.json`, the measuring form's text and the hand-written sources under `docs/guides/source/` (one topic each, loaded and converted by `guide_text.py`): the pages `docs/guides/<tool>/quick-start.md` and `full-guide.md`, and the PDFs `docs/Plug_Puller_<Tool>_Quick_Start.pdf` and `..._Full_Guide.pdf` on US Letter pages (a cover, a contents page with page numbers, the sections as cards and prose that flow down the pages with no picture above 1:1, and the 210 × 279 mm measuring form and paper stencil sheets centered at 1:1 on the last pages; the document's name at the top and "Page N of M" at the bottom of every flowing page). Every dial is a card headed by its plain title, then the name the Customizer shows, the sentence of what it does, the picture with its alt text and its long description less the clause that repeats that sentence (or a "No picture." line for a dial that changes no shape), its numbers in plain words, the parts it moves and the red warnings it can raise (a hand-kept table read off `docs/guides/source/tags-*.md`). The PDF is printed with headless Edge through `build_outline_sheets_pdf.print_to_pdf` until the contents' page numbers settle, then verified (every page US Letter, one outline entry per heading with every dial's title among them, a link per contents entry, the contents' numbers equal to the pages their links land on, the page count's bounds). `--markdown-only` needs no browser. Run both tools after `generate_dial_diagrams.py`, `generate_measuring_form.py` and `generate_stencil_sheet.py`. |
| `guide_text.py` | The hand-written text of the guides: loads one source file under `docs/guides/source/` for a tool (filling `{tool}`-style placeholders; `PLACEHOLDERS` lists them) and turns the Markdown subset the sources use into HTML for the print (headings, paragraphs, lists with an image inside an item, pipe tables, fenced code, block quotes, images, links, bold, inline code). Standard library only; tested by `tests/test_guide_text.py`. |
| `render_doc_images.py` | Render the three preview PNGs the guides embed, from today's model files with the canonical OpenSCAD binary: `docs/images/one-sided-medium-render.png` (the one-sided puller at its defaults), `docs/images/two-sided-plate-render.png` (both plates of the two-sided puller at its defaults) and `docs/images/one-sided-warning-tag-preview.png` (a 27 mm thick plug, so the W-20 warning's red text lies beside the part; a plain PNG export is a preview, so the see-through plug and the tags show). Standard library only; `--only NAME` renders one. Re-run after a model change that moves what these pictures show. |
| `check_docs.py` | The documentation gate: check `README.md` and every `docs/**/*.md` against the writing standard's mechanical rules (one H1, no skipped heading level, alt text on every image, no "click here" or "check the console", table cells of at most 22 words, no banned, hedging or retired words, every relative link resolving, no compliance claim). Prints `<file>:<line>: <rule>: <detail>` per finding and exits 1 on any; prints nothing when clean. `tests/test_docs_gate.py` runs it in the quick lane. Standard library only. |
| `scad-check.ps1` | The headless check to run after any `.scad` change, in Windows PowerShell: `powershell -ExecutionPolicy Bypass -File scripts\scad-check.ps1 -File src\Plug_Puller_Two_Sided.scad` renders the file (default `src\Plug_Puller_Parametric.scad`) to `build\check.stl` with OpenSCAD's hard warnings and parameter range checks on, using the 2026.01.03 nightly (or the path in `OPENSCAD_EXE`). `-Defines 'size=Measure my hand'` sets a dial, with or without quotes around a text value; a text value that is not one of the dial's dropdown choices counts as a warning. It prints OpenSCAD's full output, then `CHECK PASSED`, or `CHECK FAILED` when any line has `WARNING:` or `ERROR:` or no STL was written. |

## Prerequisites

- Python 3.11+ with the dev dependencies installed: `pip install -r requirements-dev.txt`
- OpenSCAD 2026.01.03+ nightly (Manifold backend) on `PATH`, or set `OPENSCAD_PATH` — needed by `regenerate_fixtures.py` and `generate_outline_sheets.py`.
- Microsoft Edge or Chrome — needed by `build_outline_sheets_pdf.py` and `build_dial_reference.py` for headless SVG-to-PDF printing.

## Historical tooling

Earlier development-era scripts (reference-mesh measurement, outline fitting, fidelity reports, DXF conversion helpers) stayed in a private development repository and are not part of this project; the comments that mention that work say "during development".

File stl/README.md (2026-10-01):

# Ready-to-print STL library

Pre-rendered, watertight STLs for every default configuration — no OpenSCAD or
Customizer needed. Pick the file that matches your plug and hand and print it.

Everything here is generated from source by
[`scripts/build_release_stls.py`](../scripts/build_release_stls.py); do not edit
the STLs by hand. Re-run that script and commit the result after any intentional
model change (the shipped files are guarded by `tests/test_shipped_stls.py`).
The files are binary STLs, which every slicer opens, and a re-run leaves a file
alone when its shape did not change.

```
stl/
  Plug-Puller/                 # 21 tools: 5 plug families x 3 hand sizes, in every file that offers them
  Measuring-Stencil/
    Visual/                    # debossed printed labels (9 files)
    Tactile/                   # raised ADA characters + braille (9 files)
```

## Plug-Puller/

Pick your **plug family**, then your **hand size** — `Small` / `Medium` /
`Large`. Medium is the reference device (start there); Small ≈ 5th-percentile
female hand, Large ≈ 95th-percentile male hand.

| Plug family | File pattern | Tool type |
| --- | --- | --- |
| Flat 2-prong lamp — NEMA 1-15 | `Plug-Puller_Flat-2-Prong-Lamp-NEMA-1-15_{Small,Medium,Large}.stl` | one-sided puller (one part) |
| Standard 3-prong — NEMA 5-15 | `Plug-Puller_Standard-3-Prong-NEMA-5-15_{Small,Medium,Large}.stl` | one-sided puller (one part) |
| Wide 2-prong appliance plug — NEMA 1-15 | `Plug-Puller_Wide-2-Prong-Appliance_{Small,Medium,Large}.stl` | one-sided puller (one part) |
| Heavy-duty extension cord — NEMA 5-15 | `Plug-Puller_Two-Sided_Round-Extension-Cord-NEMA-5-15_{Small,Medium,Large}.stl` | two-sided puller (**both plates**) |
| USB-C laptop tip | `Plug-Puller_Two-Sided_USB-C-Laptop-Tip_{Small,Medium,Large}.stl` | two-sided puller (**both plates**, Rounded sides) |
| Flat 2-prong lamp — NEMA 1-15, two-sided | `Plug-Puller_Two-Sided_Flat-2-Prong-Lamp-NEMA-1-15_{Small,Medium,Large}.stl` | two-sided puller (**both plates**) |
| Standard 3-prong — NEMA 5-15, two-sided | `Plug-Puller_Two-Sided_Standard-3-Prong-NEMA-5-15_{Small,Medium,Large}.stl` | two-sided puller (**both plates**) |

> **Each two-sided file holds both plates; flip one after printing.** Then
> zip-tie the pair face to face around the plug.

Not sure which plug you have, or which size fits? Print a
[1:1 paper outline sheet](../docs/guides/one-sided/full-guide.md#try-it-on-paper-first) or the
measuring stencil below first.

## Measuring-Stencil/

Thin measuring cards that answer the fit worksheet without a caliper. Print the
full packed set (`..._All-Cards.stl`) or just the one card you need. Two label
modes — pick **`Visual/`** for debossed printed text, or **`Tactile/`** for
raised ADA-size characters plus a fold-flat Grade 2 braille flap on every card
(see ["Match a card instead of measuring" in either quick start](../docs/guides/one-sided/quick-start.md#match-a-card-instead-of-measuring)).

| Card | Purpose |
| ---- | --- |
| `All-Cards` | the full packed set — every card on one plate |
| `P1_Lamp-Plug-Gauge` | flat 2-prong lamp plug silhouette (NEMA 1-15) |
| `P2_Standard-3-Prong-Gauge` | standard 3-prong plug silhouette (NEMA 5-15) |
| `P3_Heavy-Duty-Cord-Gauge` | heavy-duty round cord silhouette (NEMA 5-15) |
| `P4_Wide-2-Prong-Appliance-Gauge` | wide 2-prong appliance plug silhouette (NEMA 1-15) |
| `R1_Ruler-100mm` | a tactile 100 mm ruler |
| `C1_Cord-Gauge` | open-slot cord gauge that slides onto an installed cord |
| `F1_Finger-Sizing-15-25mm` | finger-sizing holes Ø 15–25 mm |
| `F2_Finger-Sizing-26-32mm` | finger-sizing holes Ø 26–32 mm |

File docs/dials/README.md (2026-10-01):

# Dial diagrams

Every dial of the one-sided puller and the two-sided puller has a picture here: the tool at the dial's default on the left with the plug in teal, an arrow with the two values, and the tool after the dial moved on the right, drawn once in black with the edges that moved in red dashes; the numbered dots on those edges match the key beside the picture.

The pictures are cut from the same OpenSCAD files you print from, at 1 unit = 1 mm. Under each picture: the long form of its text alternative, then the two values and the parts that moved.

black = the tool; teal = your plug; red dashed = the edges this dial moved; the numbers match the key beside the picture.

## One-sided puller

### The four steps

The one-sided puller, the four Customizer steps on a US vacuum plug, five stages left to right.

Five stages of the one-sided puller, left to right, the top row first, the plug end at the top; arrows numbered 1 to 4 show the steps, and red dashes mark the edges each step moved. Start, the defaults: the tool as the file opens, with a 25 mm wide plug in teal. Step 1 - Your Plug: plug length, plug width at both ends, plug thickness at both ends, cord thickness, outlet cover plate style; red on the body edge, finger holes, seat, wall notch, wing openings and zip-tie holes. Step 2 - Size: hand size, finger width, hand width; red on the body edge, finger holes, pocket, wall notch, wing openings and zip-tie holes. Step 3 - Attachment: attachment; the wing openings removed, drawn in red from the old outline. Step 4 - Cord Hook: hook side; red on the hook.

### Step 1 - Your Plug

`plug_preset`: Plug preset

Plug preset: before and after, Measure my plug to Standard 3-prong plug - NEMA 5-15; red marks 7 parts, named below.

Two top views of the one-sided puller, before left and after right, the plug end at the top. Left: the defaults, a 25 mm wide plug in teal. Right: plug preset set to Standard 3-prong plug - NEMA 5-15. Marked in red: 1, the zip-tie holes, the finger holes, the wing openings, the wall notch, the seat, the pocket and the body edge.

Before: Measure my plug. After: Standard 3-prong plug - NEMA 5-15. Moves: body edge, finger holes, pocket, seat, wall notch, wing openings, zip-tie holes.

`measure_plug_length`: Plug length

Plug length: before and after, 25.5 to 40 mm; red marks the body edge, the seat, the wall notch, the wing openings and the zip-tie holes.

Two top views of the one-sided puller, before left and after right, the plug end at the top. Left: the defaults, a 25 mm wide plug in teal. Right: plug length at 40 mm. The red line marks the pocket's length and reads 40 mm, the number you type. Marked in red: 1, the zip-tie holes: the four small holes beside the pocket. 2, the zip-tie holes and the wing openings. 3, the zip-tie holes, the wing openings, the wall notch, the seat and the body edge.

Before: 25.5. After: 40. Moves: body edge, seat, wall notch, wing openings, zip-tie holes.

`measure_plug_width_prong_end`: Plug width at the prong end

Plug width at the prong end: before and after, 25 to 32 mm; red marks 5 parts, named below.

Two top views of the one-sided puller, before left and after right, the plug end at the top. Left: the defaults, a 25 mm wide plug in teal. Right: plug width at the prong end at 32 mm. The red line marks the plug's width at the prong end and reads 32 mm, the number you type. Marked in red: 1, the zip-tie holes: the four small holes beside the pocket. 2, the wing openings: the two openings beside the pocket. 3, the wall notch, the seat and the body edge: the notch in the top edge; the round recess at the plug end; the outer outline.

Before: 25. After: 32. Moves: body edge, seat, wall notch, wing openings, zip-tie holes.

`measure_plug_width_cord_end`: Plug width at the cord end

Plug width at the cord end: before and after, 25 to 15 mm; red marks the pocket, the wing openings and the zip-tie holes.

Two top views of the one-sided puller, before left and after right, the plug end at the top. Left: the defaults, a 25 mm wide plug in teal. Right: plug width at the cord end at 15 mm: tilts the pocket's side walls to match the plug's taper, and the zip-tie holes and wing openings lean in with them. The red line marks the plug's width at the cord end and reads 15 mm, the number you type. Marked in red: 1, the zip-tie holes, the wing openings and the pocket: the four small holes beside the pocket; the two openings beside the pocket; the plug recess on the centerline.

Before: 25. After: 15. Moves: pocket, wing openings, zip-tie holes.

`measure_plug_thickness_prong_end`: Plug thickness at the prong end

Plug thickness at the prong end: before and after, 20 to 23.5 mm; red marks the pocket and the seat.

Two vertical slices of the one-sided puller at x = 0 mm, before left and after right, the top face up. Left: the defaults, the plug in teal in the cut. Right: plug thickness at the prong end at 23.5 mm: deepens or shallows the two pocket floors, the round seat and the plug recess, to suit the fatter of the two thickness numbers. The red line marks the plug's thickness at the prong end and reads 23.5 mm, the number you type. Marked in red: 1, the seat and the pocket: the round recess at the plug end; the plug recess on the centerline.

Before: 20. After: 23.5. Section at x = 0 mm. Moves: pocket, seat.

`measure_plug_thickness_cord_end`: Plug thickness at the cord end

Plug thickness at the cord end: before and after, 20 to 23.5 mm; red marks the pocket and the seat.

Two vertical slices of the one-sided puller at x = 0 mm, before left and after right, the top face up. Left: the defaults, the plug in teal in the cut. Right: plug thickness at the cord end at 23.5 mm: deepens or shallows the two pocket floors, the round seat and the plug recess, when this end is the fatter end of the plug. The red line marks the plug's thickness at the cord end and reads 23.5 mm, the number you type. Marked in red: 1, the seat and the pocket: the round recess at the plug end; the plug recess on the centerline.

Before: 20. After: 23.5. Section at x = 0 mm. Moves: pocket, seat.

`measure_cord_thickness`: Cord thickness

Cord thickness: before and after, 4 to 8 mm; red marks 6 parts, named below.

Two top views of the one-sided puller, before left and after right, the plug end at the top. Left: the defaults, a 25 mm wide plug in teal. Right: cord thickness at 8 mm. The red line marks the cord hook slot and reads 8 mm, the number you type; the slot is drawn 8.8 mm wide, so the cord slips in. Marked in red: 1, the zip-tie holes, the finger holes, the wing openings, the wall notch, the pocket and the body edge.

Before: 4. After: 8. Moves: body edge, finger holes, pocket, wall notch, wing openings, zip-tie holes.

`measure_wall_plate_style`: Outlet cover plate style

Outlet cover plate style: before and after, Standard flat plate to Oversized / Jumbo; red marks 5 parts, named below.

Two top views of the one-sided puller, before left and after right, the plug end at the top. Left: the defaults, a 25 mm wide plug in teal. Right: outlet cover plate style set to Oversized / Jumbo. Marked in red: 1, the wall notch and the body edge: the notch in the top edge; the outer outline. 2, the zip-tie holes: the four small holes beside the pocket. 3, the pocket: the plug recess on the centerline. 4, the wing openings: the two openings beside the pocket.

Before: Standard flat plate. After: Oversized / Jumbo. Moves: body edge, pocket, wall notch, wing openings, zip-tie holes.

`show_plug_preview`: Show the see-through plug

Show the see-through plug: changes no shape.

This dial changes no shape: the see-through plug is a preview aid and is never exported.

This dial changes no shape. Changes no shape: the see-through plug is a preview aid and is never exported.

### Step 2 - Size

`size`: Hand size

Hand size: before and after, Medium to Large; red marks the body edge, the finger holes, the wall notch, the wing openings and the zip-tie holes.

Two top views of the one-sided puller, before left and after right, the plug end at the top. Left: the defaults, a 25 mm wide plug in teal. Right: hand size set to Large. Marked in red: 1, the zip-tie holes: the four small holes beside the pocket, removed. 2, the finger holes: the two large holes in the lower half. 3, the zip-tie holes, the wing openings, the wall notch and the body edge.

Before: Medium. After: Large. Moves: body edge, finger holes, wall notch, wing openings, zip-tie holes.

`measure_finger_width`: Finger width

Finger width: before and after, 20 to 26 mm; red marks 7 parts, named below.

Two top views of the one-sided puller, before left and after right, the plug end at the top. Left: the defaults with hand size set to Measure my hand, a 25 mm wide plug in teal. Right: finger width at 26 mm. The red line marks a finger hole and reads 26 mm, the number you type; the hole is drawn 31.4 mm across, wider than the finger. Marked in red: 1, the zip-tie holes, the finger holes, the wing openings, the wall notch, the seat, the pocket and the body edge.

Before: 20. After: 26. Context: `size` = Measure my hand. Moves: body edge, finger holes, pocket, seat, wall notch, wing openings, zip-tie holes.

`measure_hand_width`: Hand width

Hand width: before and after, 85 to 100 mm; red marks the body edge and the wing openings.

Two top views of the one-sided puller, before left and after right, the plug end at the top. Left: the defaults with hand size set to Measure my hand, a 25 mm wide plug in teal. Right: hand width at 100 mm. The red line marks the body at its widest and reads 100 mm, the number you type; the body is drawn 80.3 mm wide, narrower than the hand, as its width is worked out from the hand width. Marked in red: 1, the wing openings and the body edge: the two openings beside the pocket; the outer outline.

Before: 85. After: 100. Context: `size` = Measure my hand. Moves: body edge, wing openings.

### Step 3 - Attachment

`attachment`: Attachment

Attachment: before and after, Zip ties + Velcro to Zip ties; red marks the wing openings.

Two top views of the one-sided puller, before left and after right, the plug end at the top. Left: the defaults, a 25 mm wide plug in teal. Right: attachment set to Zip ties: adds or removes the zip-tie holes and the wing or slot openings for the strap. Marked in red: 1, the wing openings: the two openings beside the pocket, removed. The body edge, the pocket, the seat and the wall notch stay where they were.

Before: Zip ties + Velcro. After: Zip ties. Moves: wing openings.

`velcro_style`: Strap opening style

Strap opening style: before and after, Wing to Classic slot; red marks the classic slots and the wing openings.

Two top views of the one-sided puller, before left and after right, the plug end at the top. Left: the defaults, a 25 mm wide plug in teal. Right: strap opening style set to Classic slot: swaps the curved wing openings for a pair of plain rectangular slots that lean along the body's sides. Marked in red: 1, the wing openings and the classic slots: the two openings beside the pocket; the two slots beside the pocket.

Before: Wing. After: Classic slot. Moves: classic slots, wing openings.

`strap_width`: Strap width

Strap width: changes no shape.

This dial changes no shape: it only sets the width the W-14 check compares the wing opening against.

This dial changes no shape. Changes no shape: it only sets the width the W-14 check compares the wing opening against.

### Step 4 - Cord Hook

`hook_hand`: Hook side

Hook side: before and after, Right to Left; red marks the hook.

Two top views of the one-sided puller, before left and after right, the plug end at the top. Left: the defaults, a 25 mm wide plug in teal. Right: hook side set to Left: mirrors the cord hook at the cord end so its catch faces the other side, and nothing else moves. Marked in red: 1, the hook: the cord hook slot in the bottom edge. The body edge, the pocket, the seat and the wall notch stay where they were.

Before: Right. After: Left. Moves: hook.

### Advanced - Zip Tie Placement

`zip_placement`: Zip-tie hole placement

Zip-tie hole placement: before and after, Auto to Manual; red marks the seat, the wall notch, the wing openings and the zip-tie holes.

Two top views of the one-sided puller, before left and after right, the plug end at the top. Left: the defaults, a 25 mm wide plug in teal. Right: zip-tie hole placement set to Manual. Marked in red: 1, the zip-tie holes, the wall notch and the seat: the four small holes beside the pocket; the notch in the top edge; the round recess at the plug end. 2, the wing openings: the two openings beside the pocket. 3, the zip-tie holes: the four small holes beside the pocket.

Before: Auto. After: Manual. Moves: seat, wall notch, wing openings, zip-tie holes.

`zip_row_count`: Number of zip-tie rows

Number of zip-tie rows: before and after, 2 to 3; red marks the wing openings and the zip-tie holes.

Two top views of the one-sided puller, before left and after right, the plug end at the top. Left: the defaults, a 25 mm wide plug in teal. Right: number of zip-tie rows at 3: adds or removes a pair of zip-tie holes, and the rows squeeze together when the body has no room for another. Marked in red: 1, the wing openings: the two openings beside the pocket. 2, the zip-tie holes: the four small holes beside the pocket.

Before: 2. After: 3. Moves: wing openings, zip-tie holes.

`zip_pos_1`: Zip-tie pair 1 position

Zip-tie pair 1 position: before and after, 6 to 10 mm; red marks the seat, the wall notch and the zip-tie holes.

Two top views of the one-sided puller, before left and after right, the plug end at the top. Left: the defaults with zip-tie hole placement set to Manual, a 25 mm wide plug in teal. Right: zip-tie pair 1 position at 10 mm. Marked in red: 1, the zip-tie holes, the wall notch and the seat: the four small holes beside the pocket; the notch in the top edge; the round recess at the plug end.

Before: 6. After: 10. Context: `zip_placement` = Manual. Moves: seat, wall notch, zip-tie holes.

`zip_pos_2`: Zip-tie pair 2 position

Zip-tie pair 2 position: before and after, 18 to 26 mm; red marks the wing openings and the zip-tie holes.

Two top views of the one-sided puller, before left and after right, the plug end at the top. Left: the defaults with zip-tie hole placement set to Manual, a 25 mm wide plug in teal. Right: zip-tie pair 2 position at 26 mm: slides the second pair of zip-tie holes along the plug's side, measured from the plug end. Marked in red: 1, the zip-tie holes: the four small holes beside the pocket. 2, the wing openings: the two openings beside the pocket.

Before: 18. After: 26. Context: `zip_placement` = Manual. Moves: wing openings, zip-tie holes.

`zip_pos_3`: Zip-tie pair 3 position

Zip-tie pair 3 position: before and after, 30 to 26 mm; red marks the wing openings and the zip-tie holes.

Two top views of the one-sided puller, before left and after right, the plug end at the top. Left: the defaults with zip-tie hole placement set to Manual and number of zip-tie rows set to 3, a 25 mm wide plug in teal. Right: zip-tie pair 3 position at 26 mm. Marked in red: 1, the wing openings: the two openings beside the pocket. 2, the zip-tie holes and the wing openings: the four small holes beside the pocket; the two openings beside the pocket.

Before: 30. After: 26. Context: `zip_placement` = Manual, `zip_row_count` = 3. Moves: wing openings, zip-tie holes.

`zip_edge_offset`: Zip-tie hole distance from the pocket wall

Zip-tie hole distance from the pocket wall: before and after, 4 to 8 mm; red marks the wing openings and the zip-tie holes.

Two top views of the one-sided puller, before left and after right, the plug end at the top. Left: the defaults, a 25 mm wide plug in teal. Right: zip-tie hole distance from the pocket wall at 8 mm: moves every zip-tie hole farther from or closer to the pocket wall, and the wing openings reshape around them. Marked in red: 1, the zip-tie holes: the four small holes beside the pocket. 2, the wing openings: the two openings beside the pocket.

Before: 4. After: 8. Moves: wing openings, zip-tie holes.

### Advanced - Velcro Placement

`velcro_placement`: Strap slot placement

Strap slot placement: before and after, Auto to Manual; red marks the wing openings.

Two top views of the one-sided puller, before left and after right, the plug end at the top. Left: the defaults, a 25 mm wide plug in teal. Right: strap slot placement set to Manual: switches the strap openings to a pair of plain slots that the position dial slides along the plug's side, whatever the opening style. Marked in red: 1, the wing openings: the two openings beside the pocket. The body edge, the pocket, the seat and the wall notch stay where they were.

Before: Auto. After: Manual. Moves: wing openings.

`velcro_pos`: Strap slot position

Strap slot position: before and after, 12 to 25 mm; red marks the classic slots.

Two top views of the one-sided puller, before left and after right, the plug end at the top. Left: the defaults with strap opening style set to Classic slot and strap slot placement set to Manual, a 25 mm wide plug in teal. Right: strap slot position at 25 mm: slides the pair of strap slots along the plug's side, measured from the plug end. Marked in red: 1, the classic slots: the two slots beside the pocket.

Before: 12. After: 25. Context: `velcro_style` = Classic slot, `velcro_placement` = Manual. Moves: classic slots.

### Advanced - Render Quality

`quality`: Render quality

Render quality: changes no shape.

This dial changes no shape: it only sets the number of segments in every circle and arc.

This dial changes no shape. Changes no shape: it only sets the number of segments in every circle and arc.

### Custom Mode

`reset_custom_to_medium`: Reset Custom to the Medium reference

Reset Custom to the Medium reference: before and after, false to true; red marks 4 parts, named below.

Two top views of the one-sided puller, before left and after right, the plug end at the top. Left: the defaults with hand size set to Custom, a 25 mm wide plug in teal. Right: reset Custom to the Medium reference set to true. Marked in red: 1, the zip-tie holes: the four small holes beside the pocket. 2, the wing openings: the two openings beside the pocket. 3, the finger holes: the two large holes in the lower half. 4, the zip-tie holes and the body edge.

Before: false. After: true. Context: `size` = Custom. Moves: body edge, finger holes, wing openings, zip-tie holes.

`custom_enable_auto_fit`: Auto-fit

Auto-fit: changes no shape.

This dial changes no shape. Changes no shape at the Custom defaults: it only clamps sliders that leave their safe range, and every clamp is reported in the console.

This dial changes no shape. Changes no shape at the Custom defaults: it only clamps sliders that leave their safe range, and every clamp is reported in the console.

### Body Shape (Custom size only)

`custom_puller_length`: Body length

Body length: before and after, 63.5 to 73.5 mm; red marks 6 parts, named below.

Two top views of the one-sided puller, before left and after right, the plug end at the top. Left: the defaults with hand size set to Custom, a 25 mm wide plug in teal. Right: body length at 73.5 mm. Marked in red: 1, the zip-tie holes, the wing openings, the wall notch, the seat, the pocket and the body edge.

Before: 63.5. After: 73.5. Context: `size` = Custom. Moves: body edge, pocket, seat, wall notch, wing openings, zip-tie holes.

`custom_puller_bottom_width`: Body width at the widest point

Body width at the widest point: before and after, 77.6 to 87.6 mm; red marks the body edge.

Two top views of the one-sided puller, before left and after right, the plug end at the top. Left: the defaults with hand size set to Custom, a 25 mm wide plug in teal. Right: body width at the widest point at 87.6 mm: widens the body at its widest point, just above the cord end, before the side rounding is applied. Marked in red: 1, the body edge: the outer outline. Everything else follows the outline.

Before: 77.6. After: 87.6. Context: `size` = Custom. Moves: body edge.

`custom_puller_bottom_corners`: Cord-end corner width

Cord-end corner width: before and after, 3 to 13 mm; red marks the body edge.

Two top views of the one-sided puller, before left and after right, the plug end at the top. Left: the defaults with hand size set to Custom, a 25 mm wide plug in teal. Right: cord-end corner width at 13 mm: widens the flat at the cord end where the two lower corners of the body outline sit. Marked in red: 1, the body edge: the outer outline. Everything else follows the outline.

Before: 3. After: 13. Context: `size` = Custom. Moves: body edge.

`custom_puller_top_width`: Body width at the plug end

Body width at the plug end: before and after, 31.75 to 41.75 mm; red marks the body edge and the wing openings.

Two top views of the one-sided puller, before left and after right, the plug end at the top. Left: the defaults with hand size set to Custom, a 25 mm wide plug in teal. Right: body width at the plug end at 41.75 mm: widens the plug end of the body, where the wall notch and the pocket seat sit. Marked in red: 1, the body edge: the outer outline. 2, the wing openings: the two openings beside the pocket. Everything else follows the outline.

Before: 31.75. After: 41.75. Context: `size` = Custom. Moves: body edge, wing openings.

`custom_puller_middle_width`: Body width at the middle

Body width at the middle: before and after, 57.35 to 67.35 mm; red marks the body edge and the wing openings.

Two top views of the one-sided puller, before left and after right, the plug end at the top. Left: the defaults with hand size set to Custom, a 25 mm wide plug in teal. Right: body width at the middle at 67.35 mm: widens the body at the middle control point, bulging or straightening the side edges between the widest point and the plug end. Marked in red: 1, the body edge: the outer outline. 2, the wing openings: the two openings beside the pocket. Everything else follows the outline.

Before: 57.35. After: 67.35. Context: `size` = Custom. Moves: body edge, wing openings.

`custom_puller_side_corner`: Side corner position

Side corner position: before and after, 4.65 to 14.65 mm; red marks the body edge and the wing openings.

Two top views of the one-sided puller, before left and after right, the plug end at the top. Left: the defaults with hand size set to Custom, a 25 mm wide plug in teal. Right: side corner position at 14.65 mm: moves the two widest corners of the body outline up toward the plug end or down toward the cord end. Marked in red: 1, the wing openings: the two openings beside the pocket. 2, the body edge: the outer outline. Everything else follows the outline.

Before: 4.65. After: 14.65. Context: `size` = Custom. Moves: body edge, wing openings.

`custom_body_thickness`: Body thickness

Body thickness: before and after, 6.35 to 9 mm; red marks the body edge.

Two vertical slices of the one-sided puller at y = 35 mm, before left and after right, the top face up. Left: the defaults with hand size set to Custom, the plug in teal in the cut. Right: body thickness at 9 mm: thickens the whole slab, so every hole and the pocket get deeper walls. Marked in red: 1, the body edge: the outer outline. Everything else follows the outline.

Before: 6.35. After: 9. Context: `size` = Custom. Section at y = 35 mm. Moves: body edge.

`custom_body_round_bottom_only`: Round the cord half only

Round the cord half only: before and after, true to false; red marks the body edge, the hook, the seat and the wall notch.

Two top views of the one-sided puller, before left and after right, the plug end at the top. Left: the defaults with hand size set to Custom, a 25 mm wide plug in teal. Right: round the cord half only set to false: rounds the whole outline instead of only the cord half, so the plug end loses its crisp corners. Marked in red: 1, the wall notch and the seat: the notch in the top edge; the round recess at the plug end.

Before: true. After: false. Context: `size` = Custom. Moves: body edge, hook, seat, wall notch.

### Plug Pocket (Custom size only)

`custom_pocket_seat_diameter`: Pocket seat diameter

Pocket seat diameter: before and after, 31.75 to 28 mm; red marks the seat.

Two top views of the one-sided puller, before left and after right, the plug end at the top. Left: the defaults with hand size set to Custom, a 25 mm wide plug in teal. Right: pocket seat diameter at 28 mm: widens the round seat cut into the plug end of the pocket. Marked in red: 1, the seat: the round recess at the plug end. The body edge, the pocket, the wall notch and the wing openings stay where they were.

Before: 31.75. After: 28. Context: `size` = Custom. Moves: seat.

`custom_pocket_width`: Pocket width

Pocket width: before and after, 28.85 to 34 mm; red marks the pocket, the seat, the wing openings and the zip-tie holes.

Two top views of the one-sided puller, before left and after right, the plug end at the top. Left: the defaults with hand size set to Custom, a 25 mm wide plug in teal. Right: pocket width at 34 mm. Marked in red: 1, the seat and the pocket: the round recess at the plug end; the plug recess on the centerline. 2, the zip-tie holes: the four small holes beside the pocket. 3, the wing openings: the two openings beside the pocket.

Before: 28.85. After: 34. Context: `size` = Custom. Moves: pocket, seat, wing openings, zip-tie holes.

`custom_pocket_depth`: Pocket depth

Pocket depth: before and after, 24.5 to 34 mm; red marks the pocket and the wing openings.

Two top views of the one-sided puller, before left and after right, the plug end at the top. Left: the defaults with hand size set to Custom, a 25 mm wide plug in teal. Right: pocket depth at 34 mm: runs the plug recess farther from the plug end toward the finger holes. Marked in red: 1, the pocket: the plug recess on the centerline. 2, the wing openings: the two openings beside the pocket.

Before: 24.5. After: 34. Context: `size` = Custom. Moves: pocket, wing openings.

`custom_pocket_dome_drop`: Pocket reference drop

Pocket reference drop: changes no shape.

This dial changes no shape: the recess is a rounded-nose shape whose width at the plug end is the pocket width and whose walls follow the side taper, so this reference point cancels out; measured with straight and with tapered walls.

This dial changes no shape. Changes no shape: the recess is a rounded-nose shape whose width at the plug end is the pocket width and whose walls follow the side taper, so this reference point cancels out; measured with straight and with tapered walls.

`custom_pocket_seat_floor`: Pocket seat floor thickness

Pocket seat floor thickness: before and after, 3.175 to 1.5 mm; red marks the seat.

Two vertical slices of the one-sided puller at x = 0 mm, before left and after right, the top face up. Left: the defaults with hand size set to Custom, the plug in teal in the cut. Right: pocket seat floor thickness at 1.5 mm: thins or thickens the floor left under the round seat, so the seat is cut deeper or shallower. Marked in red: 1, the seat: the round recess at the plug end.

Before: 3.175. After: 1.5. Context: `size` = Custom. Section at x = 0 mm. Moves: seat.

`custom_pocket_floor`: Plug recess floor thickness

Plug recess floor thickness: before and after, 3.81 to 2 mm; red marks the pocket and the seat.

Two vertical slices of the one-sided puller at x = 0 mm, before left and after right, the top face up. Left: the defaults with hand size set to Custom, the plug in teal in the cut. Right: plug recess floor thickness at 2 mm: thins or thickens the floor left under the plug recess, so the recess is cut deeper or shallower. Marked in red: 1, the seat and the pocket: the round recess at the plug end; the plug recess on the centerline.

Before: 3.81. After: 2. Context: `size` = Custom. Section at x = 0 mm. Moves: pocket, seat.

`custom_pocket_side_angle`: Pocket side taper

Pocket side taper: before and after, 0 to 10 mm; red marks the pocket, the wing openings and the zip-tie holes.

Two top views of the one-sided puller, before left and after right, the plug end at the top. Left: the defaults with hand size set to Custom, a 25 mm wide plug in teal. Right: pocket side taper at 10 mm. Marked in red: 1, the zip-tie holes, the wing openings and the pocket: the four small holes beside the pocket; the two openings beside the pocket; the plug recess on the centerline.

Before: 0. After: 10. Context: `size` = Custom. Moves: pocket, wing openings, zip-tie holes.

### Finger Holes (Custom size only)

`custom_enable_finger_holes`: Finger holes on or off

Finger holes on or off: before and after, true to false; red marks the body edge and the finger holes.

Two top views of the one-sided puller, before left and after right, the plug end at the top. Left: the defaults with hand size set to Custom, a 25 mm wide plug in teal. Right: finger holes on or off set to false: cuts or leaves out both finger holes. Marked in red: 1, the finger holes and the body edge: the two large holes in the lower half; the outer outline, removed. Everything else follows the outline.

Before: true. After: false. Context: `size` = Custom. Moves: body edge, finger holes.

`custom_finger_hole_diameter`: Finger hole diameter

Finger hole diameter: before and after, 25.4 to 22 mm; red marks the finger holes and the wing openings.

Two top views of the one-sided puller, before left and after right, the plug end at the top. Left: the defaults with hand size set to Custom, a 25 mm wide plug in teal. Right: finger hole diameter at 22 mm: widens both finger holes. Marked in red: 1, the wing openings: the two openings beside the pocket. 2, the finger holes: the two large holes in the lower half. The body edge, the pocket, the seat and the wall notch stay where they were.

Before: 25.4. After: 22. Context: `size` = Custom. Moves: finger holes, wing openings.

`custom_finger_hole_spacing`: Finger hole spacing

Finger hole spacing: before and after, 33 to 40 mm; red marks the finger holes and the wing openings.

Two top views of the one-sided puller, before left and after right, the plug end at the top. Left: the defaults with hand size set to Custom, a 25 mm wide plug in teal. Right: finger hole spacing at 40 mm: moves the two finger holes farther apart or closer together. Marked in red: 1, the wing openings: the two openings beside the pocket. 2, the finger holes: the two large holes in the lower half.

Before: 33. After: 40. Context: `size` = Custom. Moves: finger holes, wing openings.

`custom_finger_hole_y_position`: Finger hole position

Finger hole position: before and after, 19.8 to 26 mm; red marks the finger holes, the pocket, the wing openings and the zip-tie holes.

Two top views of the one-sided puller, before left and after right, the plug end at the top. Left: the defaults with hand size set to Custom, a 25 mm wide plug in teal. Right: finger hole position at 26 mm. Marked in red: 1, the zip-tie holes and the pocket. 2, the zip-tie holes, the finger holes and the wing openings.

Before: 19.8. After: 26. Context: `size` = Custom. Moves: finger holes, pocket, wing openings, zip-tie holes.

### T Hook (Custom size only)

`custom_enable_t_hook`: Cord hook on or off

Cord hook on or off: before and after, true to false; red marks the hook.

Two top views of the one-sided puller, before left and after right, the plug end at the top. Left: the defaults with hand size set to Custom, a 25 mm wide plug in teal. Right: cord hook on or off set to false: cuts or leaves out the cord hook at the cord end. Marked in red: 1, the hook: the cord hook slot in the bottom edge. The body edge, the pocket, the seat and the wall notch stay where they were.

Before: true. After: false. Context: `size` = Custom. Moves: hook.

`custom_t_hook_base_gap`: Hook slot width

Hook slot width: before and after, 4.7625 to 7 mm; red marks the hook.

Two top views of the one-sided puller, before left and after right, the plug end at the top. Left: the defaults with hand size set to Custom, a 25 mm wide plug in teal. Right: hook slot width at 7 mm: widens the slot the cord slides into at the cord end. Marked in red: 1, the hook: the cord hook slot in the bottom edge. The body edge, the pocket, the seat and the wall notch stay where they were.

Before: 4.7625. After: 7. Context: `size` = Custom. Moves: hook.

`custom_t_hook_length`: Hook length

Hook length: before and after, 10.16 to 15 mm; red marks the finger holes, the hook, the pocket, the wing openings and the zip-tie holes.

Two top views of the one-sided puller, before left and after right, the plug end at the top. Left: the defaults with hand size set to Custom, a 25 mm wide plug in teal. Right: hook length at 15 mm: runs the cord hook farther into the body from the cord end. Marked in red: 1, the finger holes: the two large holes in the lower half. 2, the finger holes and the hook: the two large holes in the lower half; the cord hook slot in the bottom edge.

Before: 10.16. After: 15. Context: `size` = Custom. Moves: finger holes, hook, pocket, wing openings, zip-tie holes.

`custom_t_hook_holder_width`: Hook crossbar width

Hook crossbar width: before and after, 11.1125 to 16 mm; red marks the finger holes, the hook, the wing openings and the zip-tie holes.

Two top views of the one-sided puller, before left and after right, the plug end at the top. Left: the defaults with hand size set to Custom, a 25 mm wide plug in teal. Right: hook crossbar width at 16 mm. Marked in red: 1, the finger holes and the hook: the two large holes in the lower half; the cord hook slot in the bottom edge. 2, the finger holes: the two large holes in the lower half.

Before: 11.1125. After: 16. Context: `size` = Custom. Moves: finger holes, hook, wing openings, zip-tie holes.

`custom_t_hook_holder_length`: Hook crossbar height

Hook crossbar height: before and after, 5.08 to 8 mm; red marks the hook.

Two top views of the one-sided puller, before left and after right, the plug end at the top. Left: the defaults with hand size set to Custom, a 25 mm wide plug in teal. Right: hook crossbar height at 8 mm: makes the crossbar opening taller or shorter along the body. Marked in red: 1, the hook: the cord hook slot in the bottom edge. The body edge, the pocket, the seat and the wall notch stay where they were.

Before: 5.08. After: 8. Context: `size` = Custom. Moves: hook.

`custom_t_hook_gap_offset`: Hook slot inset

Hook slot inset: changes no shape.

This dial changes no shape: the J-hook cord catch is drawn without this dial; it only appears in the Cutouts Only 2D debug overlay.

This dial changes no shape. Changes no shape: the J-hook cord catch is drawn without this dial; it only appears in the Cutouts Only 2D debug overlay.

`custom_t_hook_leg_offset`: Hook stem side offset

Hook stem side offset: before and after, 0 to 3 mm; red marks the finger holes, the wing openings and the zip-tie holes.

Two top views of the one-sided puller, before left and after right, the plug end at the top. Left: the defaults with hand size set to Custom, a 25 mm wide plug in teal. Right: hook stem side offset at 3 mm. Marked in red: 1, the wing openings: the two openings beside the pocket. 2, the zip-tie holes: the four small holes beside the pocket. 3, the finger holes: the two large holes in the lower half.

Before: 0. After: 3. Context: `size` = Custom. Moves: finger holes, wing openings, zip-tie holes.

`custom_t_hook_stem_offset`: Hook stem offset

Hook stem offset: before and after, 4.5 to 7 mm; red marks the hook.

Two top views of the one-sided puller, before left and after right, the plug end at the top. Left: the defaults with hand size set to Custom, a 25 mm wide plug in teal. Right: hook stem offset at 7 mm: shifts the cord slot sideways along the crossbar, making the J of the hook deeper or shallower. Marked in red: 1, the hook: the cord hook slot in the bottom edge. The body edge, the pocket, the seat and the wall notch stay where they were.

Before: 4.5. After: 7. Context: `size` = Custom. Moves: hook.

`custom_t_hook_catch_reach`: Hook catch reach

Hook catch reach: before and after, 4.55 to 8 mm; red marks the hook.

Two top views of the one-sided puller, before left and after right, the plug end at the top. Left: the defaults with hand size set to Custom, a 25 mm wide plug in teal. Right: hook catch reach at 8 mm: extends the crossbar past the slot on the catch side, lengthening the lip the cord hooks under. Marked in red: 1, the hook: the cord hook slot in the bottom edge. The body edge, the pocket, the seat and the wall notch stay where they were.

Before: 4.55. After: 8. Context: `size` = Custom. Moves: hook.

`custom_t_hook_tip_drop`: Hook tip drop

Hook tip drop: changes no shape.

This dial changes no shape. Only acts when size is Custom. Changes no shape: the hook slot's mouth already opens through the cord end (the body ends at Y = 0), so sagging the mouth farther below that edge cuts only air; measured at 1.98, 4 and 0.

This dial changes no shape. Only acts when size is Custom. Changes no shape: the hook slot's mouth already opens through the cord end (the body ends at Y = 0), so sagging the mouth farther below that edge cuts only air; measured at 1.98, 4 and 0.

### Plug Wall Notch (Custom size only)

`custom_enable_plug_wall_notch`: Wall notch on or off

Wall notch on or off: before and after, true to false; red marks the wall notch.

Two top views of the one-sided puller, before left and after right, the plug end at the top. Left: the defaults with hand size set to Custom, a 25 mm wide plug in teal. Right: wall notch on or off set to false: cuts or leaves out the notch at the plug end that straddles the outlet's cover plate. Marked in red: 1, the wall notch: the notch in the top edge. The body edge, the pocket, the seat and the wing openings stay where they were.

Before: true. After: false. Context: `size` = Custom. Moves: wall notch.

`custom_plug_wall_notch_width`: Wall notch width

Wall notch width: before and after, 26.67 to 20 mm; red marks the wall notch.

Two top views of the one-sided puller, before left and after right, the plug end at the top. Left: the defaults with hand size set to Custom, a 25 mm wide plug in teal. Right: wall notch width at 20 mm: widens or narrows the notch at the plug end. Marked in red: 1, the wall notch: the notch in the top edge. The body edge, the pocket, the seat and the wing openings stay where they were.

Before: 26.67. After: 20. Context: `size` = Custom. Moves: wall notch.

`custom_plug_wall_notch_height`: Wall notch depth

Wall notch depth: before and after, 3.81 to 7 mm; red marks the wall notch, the wing openings and the zip-tie holes.

Two top views of the one-sided puller, before left and after right, the plug end at the top. Left: the defaults with hand size set to Custom, a 25 mm wide plug in teal. Right: wall notch depth at 7 mm: cuts the notch deeper or shallower into the plug end. Marked in red: 1, the zip-tie holes and the wall notch: the four small holes beside the pocket; the notch in the top edge. The body edge, the pocket, the seat and the wing openings stay where they were.

Before: 3.81. After: 7. Context: `size` = Custom. Moves: wall notch, wing openings, zip-tie holes.

`custom_plug_wall_notch_rounding`: Wall notch corner rounding

Wall notch corner rounding: before and after, 2.54 to 0 mm; red marks the wall notch.

Two top views of the one-sided puller, before left and after right, the plug end at the top. Left: the defaults with hand size set to Custom, a 25 mm wide plug in teal. Right: wall notch corner rounding at 0 mm: rounds or squares the notch's two inner corners. Marked in red: 1, the wall notch: the notch in the top edge. The body edge, the pocket, the seat and the wing openings stay where they were.

Before: 2.54. After: 0. Context: `size` = Custom. Moves: wall notch.

### Zip Tie Holes (Custom size only)

`custom_zip_tie_hole_diameter`: Zip-tie hole diameter

Zip-tie hole diameter: before and after, 5.08 to 7 mm; red marks the wing openings and the zip-tie holes.

Two top views of the one-sided puller, before left and after right, the plug end at the top. Left: the defaults with hand size set to Custom, a 25 mm wide plug in teal. Right: zip-tie hole diameter at 7 mm: widens every zip-tie hole. Marked in red: 1, the zip-tie holes: the four small holes beside the pocket. 2, the wing openings: the two openings beside the pocket. The body edge, the pocket, the seat and the wall notch stay where they were.

Before: 5.08. After: 7. Context: `size` = Custom. Moves: wing openings, zip-tie holes.

`custom_zip_tie_height_spacing`: Zip-tie row spacing

Zip-tie row spacing: before and after, 17.78 to 12 mm; red marks the wing openings and the zip-tie holes.

Two top views of the one-sided puller, before left and after right, the plug end at the top. Left: the defaults with hand size set to Custom, a 25 mm wide plug in teal. Right: zip-tie row spacing at 12 mm: moves the second row of zip-tie holes closer to or farther from the first. Marked in red: 1, the wing openings: the two openings beside the pocket. 2, the zip-tie holes: the four small holes beside the pocket.

Before: 17.78. After: 12. Context: `size` = Custom. Moves: wing openings, zip-tie holes.

`custom_zip_tie_width_spacing`: Zip-tie column spacing

Zip-tie column spacing: changes no shape.

This dial changes no shape. Changes no shape of its own: the zip-tie columns sit zip_edge_offset inside the pocket wall; this dial only feeds the auto-fit finger keep-out, which trimmed the row spacing by 0.05 mm at the Custom defaults.

This dial changes no shape. Changes no shape of its own: the zip-tie columns sit zip_edge_offset inside the pocket wall; this dial only feeds the auto-fit finger keep-out, which trimmed the row spacing by 0.05 mm at the Custom defaults.

`custom_zip_tie_distance_from_notch`: Zip-tie distance from the notch

Zip-tie distance from the notch: before and after, 5.1 to 9 mm; red marks the wing openings and the zip-tie holes.

Two top views of the one-sided puller, before left and after right, the plug end at the top. Left: the defaults with hand size set to Custom, a 25 mm wide plug in teal. Right: zip-tie distance from the notch at 9 mm: moves the first row of zip-tie holes farther from the wall notch, and the second row follows. Marked in red: 1, the zip-tie holes: the four small holes beside the pocket. 2, the wing openings: the two openings beside the pocket.

Before: 5.1. After: 9. Context: `size` = Custom. Moves: wing openings, zip-tie holes.

`custom_zip_tie_countersink`: Zip-tie countersink

Zip-tie countersink: before and after, 0.9 to 2.5 mm; red marks the pocket and the zip-tie holes.

Two vertical slices of the one-sided puller at x = 10.4 mm, before left and after right, the top face up. Left: the defaults with hand size set to Custom, the plug in teal in the cut. Right: zip-tie countersink at 2.5 mm. Marked in red: 1, the zip-tie holes: the four small holes beside the pocket. 2, the zip-tie holes and the pocket: the four small holes beside the pocket; the plug recess on the centerline.

Before: 0.9. After: 2.5. Context: `size` = Custom. Section at x = 10.4 mm. Moves: pocket, zip-tie holes.

### Velcro / Wing Strap Holes (Custom size only)

`custom_velcro_hole_length`: Strap slot length

Strap slot length: before and after, 12 to 18 mm; red marks the classic slots.

Two top views of the one-sided puller, before left and after right, the plug end at the top. Left: the defaults with hand size set to Custom and strap opening style set to Classic slot, a 25 mm wide plug in teal. Right: strap slot length at 18 mm: lengthens each plain strap slot along its lean. Marked in red: 1, the classic slots: the two slots beside the pocket. The body edge, the pocket, the seat and the wall notch stay where they were.

Before: 12. After: 18. Context: `size` = Custom, `velcro_style` = Classic slot. Moves: classic slots.

`custom_velcro_hole_width`: Strap slot width

Strap slot width: before and after, 7 to 11 mm; red marks the classic slots.

Two top views of the one-sided puller, before left and after right, the plug end at the top. Left: the defaults with hand size set to Custom and strap opening style set to Classic slot, a 25 mm wide plug in teal. Right: strap slot width at 11 mm: widens each plain strap slot. Marked in red: 1, the classic slots: the two slots beside the pocket. The body edge, the pocket, the seat and the wall notch stay where they were.

Before: 7. After: 11. Context: `size` = Custom, `velcro_style` = Classic slot. Moves: classic slots.

`custom_velcro_hole_x_center`: Strap slot distance from the centerline

Strap slot distance from the centerline: before and after, 19.4 to 14 mm; red marks the classic slots.

Two top views of the one-sided puller, before left and after right, the plug end at the top. Left: the defaults with hand size set to Custom and strap opening style set to Classic slot, a 25 mm wide plug in teal. Right: strap slot distance from the centerline at 14 mm: moves the two plain strap slots closer to or farther from the centerline. Marked in red: 1, the classic slots: the two slots beside the pocket.

Before: 19.4. After: 14. Context: `size` = Custom, `velcro_style` = Classic slot. Moves: classic slots.

`custom_velcro_hole_y_center`: Strap slot position along the body

Strap slot position along the body: before and after, 46 to 38 mm; red marks the classic slots.

Two top views of the one-sided puller, before left and after right, the plug end at the top. Left: the defaults with hand size set to Custom and strap opening style set to Classic slot, a 25 mm wide plug in teal. Right: strap slot position along the body at 38 mm: slides the two plain strap slots toward the cord end or the plug end. Marked in red: 1, the classic slots: the two slots beside the pocket.

Before: 46. After: 38. Context: `size` = Custom, `velcro_style` = Classic slot. Moves: classic slots.

`custom_velcro_hole_rotation`: Strap slot lean

Strap slot lean: before and after, 23.5 to 60 deg; red marks the classic slots.

Two top views of the one-sided puller, before left and after right, the plug end at the top. Left: the defaults with hand size set to Custom and strap opening style set to Classic slot, a 25 mm wide plug in teal. Right: strap slot lean at 60 deg: leans the two plain strap slots more or less steeply, mirrored on the two sides. Marked in red: 1, the classic slots: the two slots beside the pocket.

Before: 23.5. After: 60. Context: `size` = Custom, `velcro_style` = Classic slot. Moves: classic slots.

### Edge Rounding (Custom size only)

`custom_body_side_rounding`: Body side rounding

Body side rounding: before and after, 15.85 to 5 mm; red marks the body edge.

Two top views of the one-sided puller, before left and after right, the plug end at the top. Left: the defaults with hand size set to Custom, a 25 mm wide plug in teal. Right: body side rounding at 5 mm: rounds the body outline's corners more or less, down to the plain octagon at 0. Marked in red: 1, the body edge: the outer outline. Everything else follows the outline.

Before: 15.85. After: 5. Context: `size` = Custom. Moves: body edge.

`custom_body_top_rounding`: Top edge rounding

Top edge rounding: before and after, 2.54 to 0 mm; red marks the body edge.

Two vertical slices of the one-sided puller at y = 35 mm, before left and after right, the top face up. Left: the defaults with hand size set to Custom, the plug in teal in the cut. Right: top edge rounding at 0 mm: rounds or squares the edge where the body's top face meets its sides. Marked in red: 1, the body edge: the outer outline. Everything else follows the outline.

Before: 2.54. After: 0. Context: `size` = Custom. Section at y = 35 mm. Moves: body edge.

`custom_body_bottom_rounding`: Bottom edge rounding

Bottom edge rounding: before and after, 0 to 2 mm; red marks the body edge.

Two vertical slices of the one-sided puller at y = 35 mm, before left and after right, the top face up. Left: the defaults with hand size set to Custom, the plug in teal in the cut. Right: bottom edge rounding at 2 mm: rounds or squares the edge where the body's bottom face meets its sides. Marked in red: 1, the body edge: the outer outline. Everything else follows the outline.

Before: 0. After: 2. Context: `size` = Custom. Section at y = 35 mm. Moves: body edge.

`custom_velcro_side_rounding`: Strap slot corner rounding

Strap slot corner rounding: before and after, 0 to 2.5 mm; red marks the classic slots.

Two top views of the one-sided puller, before left and after right, the plug end at the top. Left: the defaults with hand size set to Custom and strap opening style set to Classic slot, a 25 mm wide plug in teal. Right: strap slot corner rounding at 2.5 mm: rounds the four corners of each plain strap slot. Marked in red: 1, the classic slots: the two slots beside the pocket. The body edge, the pocket, the seat and the wall notch stay where they were.

Before: 0. After: 2.5. Context: `size` = Custom, `velcro_style` = Classic slot. Moves: classic slots.

`custom_velcro_top_bottom_rounding`: Strap opening edge rounding

Strap opening edge rounding: before and after, 0 to 1.5 mm; red marks the pocket and the wing openings.

Two vertical slices of the one-sided puller at y = 46 mm, before left and after right, the top face up. Left: the defaults with hand size set to Custom, the plug in teal in the cut. Right: strap opening edge rounding at 1.5 mm. Marked in red: 1, the wing openings: the two openings beside the pocket. 2, the wing openings and the pocket: the two openings beside the pocket; the plug recess on the centerline.

Before: 0. After: 1.5. Context: `size` = Custom. Section at y = 46 mm. Moves: pocket, wing openings.

`custom_finger_hole_rounding`: Finger hole rim rounding

Finger hole rim rounding: before and after, 2.5 to 0 mm; red marks the finger holes.

Two vertical slices of the one-sided puller at y = 19.8 mm, before left and after right, the top face up. Left: the defaults with hand size set to Custom, the plug in teal in the cut. Right: finger hole rim rounding at 0 mm: rounds or squares the rims of both finger holes on both faces. Marked in red: 1, the finger holes: the two large holes in the lower half. The body edge, the pocket, the seat and the wall notch stay where they were.

Before: 2.5. After: 0. Context: `size` = Custom. Section at y = 19.8 mm. Moves: finger holes.

`custom_t_hook_holder_side_rounding`: Hook crossbar corner rounding

Hook crossbar corner rounding: before and after, 1.27 to 0 mm; red marks the hook.

Two top views of the one-sided puller, before left and after right, the plug end at the top. Left: the defaults with hand size set to Custom, a 25 mm wide plug in teal. Right: hook crossbar corner rounding at 0 mm: rounds or squares the top corners of the hook's crossbar. Marked in red: 1, the hook: the cord hook slot in the bottom edge. The body edge, the pocket, the seat and the wall notch stay where they were.

Before: 1.27. After: 0. Context: `size` = Custom. Moves: hook.

`custom_t_hook_gap_side_rounding`: Hook slot corner rounding

Hook slot corner rounding: changes no shape.

This dial changes no shape: the J-hook cord catch is drawn without this dial; it only appears in the Cutouts Only 2D debug overlay.

This dial changes no shape. Changes no shape: the J-hook cord catch is drawn without this dial; it only appears in the Cutouts Only 2D debug overlay.

`custom_t_hook_top_bottom_rounding`: Hook edge rounding

Hook edge rounding: before and after, 0 to 2 mm; red marks the hook.

Two vertical slices of the one-sided puller at x = 4.5 mm, before left and after right, the top face up. Left: the defaults with hand size set to Custom, the plug in teal in the cut. Right: hook edge rounding at 2 mm: flares the top and bottom edges of the cord hook's slot and crossbar. Marked in red: 1, the hook: the cord hook slot in the bottom edge. The body edge, the pocket, the seat and the wall notch stay where they were.

Before: 0. After: 2. Context: `size` = Custom. Section at x = 4.5 mm. Moves: hook.

## Two-sided puller

### The four steps

The two-sided puller, the four Customizer steps on a USB-C laptop plug, five stages left to right.

Five stages of the two-sided puller, left to right, the top row first, the plug end at the top; arrows numbered 1 to 4 show the steps, and red dashes mark the edges each step moved. Start, the defaults: the tool as the file opens, with a 20 mm wide plug in teal. Step 1 - Your Plug: plug length 23 mm, plug width at both ends 13 mm, cord thickness 7 mm, plug sides Rounded sides; red on the arms, the finger lobes and the zip stations. Step 2 - Size: hand size Large; red on the arms, the finger lobes and the zip stations. Step 3 - Attachment: attachment Zip ties; no strap slot on a plug this short, so nothing moved. Step 4 - Print Layout: both plates side by side in one file, what you print; nothing marked.

### Step 1 - Your Plug

`plug_preset`: Plug preset

Plug preset: before and after, Measure my plug to Heavy-duty extension cord - NEMA 5-15; red marks 5 parts, named below.

Two top views of one plate of the two-sided puller, before left and after right, the plug end at the top. Left: the defaults, a 20 mm wide plug in teal. Right: plug preset set to Heavy-duty extension cord - NEMA 5-15. Marked in red: 1, the zip stations, the strap slot, the finger lobes, the arms and the plate edge. 2, the finger lobes: the two rounded lobes in the lower half. 3, the zip stations: the three small holes along each arm.

Before: Measure my plug. After: Heavy-duty extension cord - NEMA 5-15. Moves: arms, finger lobes, plate edge, strap slot, zip stations.

`measure_plug_length`: Plug length

Plug length: before and after, 25.5 to 40 mm; red marks the arms, the strap slot and the zip stations.

Two top views of one plate of the two-sided puller, before left and after right, the plug end at the top. Left: the defaults, a 20 mm wide plug in teal. Right: plug length at 40 mm: lengthens both arms so the teeth cover the whole plug body, and moves the zip-tie stations and the strap slot with them. The red line marks the plug's length and reads 40 mm, the number you type. Marked in red: 1, the zip stations, the strap slot and the arms: the three small holes along each arm; the long slot in each arm; the two toothed arms in the upper half.

Before: 25.5. After: 40. Moves: arms, strap slot, zip stations.

`measure_plug_width_prong_end`: Plug width at the prong end

Plug width at the prong end: before and after, 20 to 28 mm; red marks the arms, the cord channel, the finger lobes and the zip stations.

Two top views of one plate of the two-sided puller, before left and after right, the plug end at the top. Left: the defaults, a 20 mm wide plug in teal. Right: plug width at the prong end at 28 mm. The red line marks the gap between the arm tips and reads 28 mm, the number you type. Marked in red: 1, the zip stations and the arms. 2, the zip stations: the three small holes along each arm. 3, the finger lobes and the cord channel.

Before: 20. After: 28. Moves: arms, cord channel, finger lobes, zip stations.

`measure_plug_width_cord_end`: Plug width at the cord end

Plug width at the cord end: before and after, 20 to 12 mm; red marks the arms, the teeth and the zip stations.

Two top views of one plate of the two-sided puller, before left and after right, the plug end at the top. Left: the defaults, a 20 mm wide plug in teal. Right: plug width at the cord end at 12 mm. The red line marks the gap between the arms at the cord end and reads 12 mm, the number you type. Marked in red: 1, the zip stations: the three small holes along each arm. 2, the zip stations, the teeth and the arms: the three small holes along each arm; the serrated inner edges of the arms; the two toothed arms in the upper half.

Before: 20. After: 12. Moves: arms, teeth, zip stations.

`measure_cord_thickness`: Cord thickness

Cord thickness: before and after, 4 to 9 mm; red marks the arms, the cord channel, the finger lobes and the zip stations.

Two top views of one plate of the two-sided puller, before left and after right, the plug end at the top. Left: the defaults, a 20 mm wide plug in teal. Right: cord thickness at 9 mm. The red line marks the cord channel and reads 9 mm, the number you type; the channel is drawn 9.8 mm wide, so the cord slips in. Marked in red: 1, the finger lobes and the cord channel. 2, the finger lobes: the two rounded lobes in the lower half. 3, the finger lobes and the arms. 4, the zip stations: the three small holes along each arm.

Before: 4. After: 9. Moves: arms, cord channel, finger lobes, zip stations.

`plug_sides`: Plug sides

Plug sides: before and after, Rounded sides to Flat sides; red marks the arms and the teeth.

Two vertical slices of the two-sided puller at y = 45 mm, before left and after right, the top face up. Left: the defaults, the plug in teal in the cut. Right: plug sides set to Flat sides. Marked in red: 1, the teeth and the arms: the serrated inner edges of the arms; the two toothed arms in the upper half. 2, the arms: the two toothed arms in the upper half.

Before: Rounded sides. After: Flat sides. Section at y = 45 mm. Moves: arms, teeth.

`show_plug_preview`: Show the see-through plug

Show the see-through plug: changes no shape.

This dial changes no shape: the see-through plug is a preview aid and is never exported.

This dial changes no shape. Changes no shape: the see-through plug is a preview aid and is never exported.

### Step 2 - Size

`size`: Hand size

Hand size: before and after, Medium to Large; red marks the arms, the finger lobes and the zip stations.

Two top views of one plate of the two-sided puller, before left and after right, the plug end at the top. Left: the defaults, a 20 mm wide plug in teal. Right: hand size set to Large. Marked in red: 1, the zip stations: the three small holes along each arm. 2, the finger lobes and the arms: the two rounded lobes in the lower half; the two toothed arms in the upper half. 3, the finger lobes: the two rounded lobes in the lower half.

Before: Medium. After: Large. Moves: arms, finger lobes, zip stations.

`measure_finger_width`: Finger width

Finger width: before and after, 20 to 26 mm; red marks the arms, the finger lobes, the plate edge and the zip stations.

Two top views of one plate of the two-sided puller, before left and after right, the plug end at the top. Left: the defaults with hand size set to Measure my hand, a 20 mm wide plug in teal. Right: finger width at 26 mm. The red line marks a finger hole and reads 26 mm, the number you type; the hole is drawn 27 mm across, wider than the finger. Marked in red: 1, the zip stations: the three small holes along each arm. 2, the zip stations, the finger lobes, the arms and the plate edge.

Before: 20. After: 26. Context: `size` = Measure my hand. Moves: arms, finger lobes, plate edge, zip stations.

### Step 3 - Attachment

`attachment`: Attachment

Attachment: before and after, Zip ties + Velcro strap to Zip ties; red marks the arms, the strap slot and the zip stations.

Two top views of one plate of the two-sided puller, before left and after right, the plug end at the top. Left: the defaults with plug length set to 40, a 20 mm wide plug in teal. Right: attachment set to Zip ties. Marked in red: 1, the zip stations: the three small holes along each arm. 2, the strap slot and the arms: the long slot in each arm; the two toothed arms in the upper half.

Before: Zip ties + Velcro strap. After: Zip ties. Context: `measure_plug_length` = 40. Moves: arms, strap slot, zip stations.

`strap_width`: Strap width

Strap width: before and after, 15 to 25 mm; red marks the arms, the strap slot and the zip stations.

Two top views of one plate of the two-sided puller, before left and after right, the plug end at the top. Left: the defaults with plug length set to 40, a 20 mm wide plug in teal. Right: strap width at 25 mm. Marked in red: 1, the zip stations: the three small holes along each arm. 2, the strap slot and the arms: the long slot in each arm; the two toothed arms in the upper half.

Before: 15. After: 25. Context: `measure_plug_length` = 40. Moves: arms, strap slot, zip stations.

### Step 4 - Print Layout

`print_layout`: Print layout

Print layout: one view, Both plates to One plate; the layout with both plates, nothing marked.

One top view of the two-sided puller with both plates side by side, the plug end at the top: what the file prints at Both plates. At One plate it prints one plate. Nothing is marked in red: this dial changes the layout, not the plate.

Before: Both plates. After: One plate. Moves: arms, finger lobes, plate edge, zip stations.

### Advanced - Two-Sided Puller

`plate_wall_boost`: Extra wall on the plate

Extra wall on the plate: before and after, 0 to 2 mm; red marks the arms, the finger lobes and the zip stations.

Two top views of one plate of the two-sided puller, before left and after right, the plug end at the top. Left: the defaults, a 20 mm wide plug in teal. Right: extra wall on the plate at 2 mm. Marked in red: 1, the zip stations: the three small holes along each arm. 2, the finger lobes and the arms: the two rounded lobes in the lower half; the two toothed arms in the upper half. 3, the finger lobes: the two rounded lobes in the lower half.

Before: 0. After: 2. Moves: arms, finger lobes, zip stations.

`plate_thickness`: Plate thickness

Plate thickness: before and after, 4 to 6 mm; red marks the cord channel, the finger lobes and the zip stations.

Two vertical slices of the two-sided puller at y = 3 mm, before left and after right, the top face up. Left: the defaults, the plug in teal in the cut. Right: plate thickness at 6 mm. Marked in red: 1, the finger lobes: the two rounded lobes in the lower half. 2, the zip stations, the finger lobes and the cord channel: the three small holes along each arm; the two rounded lobes in the lower half; the gap between the lobes at the bottom.

Before: 4. After: 6. Section at y = 3 mm. Moves: cord channel, finger lobes, zip stations.

`plate_grip_bite`: Grip bite

Grip bite: before and after, -1 to -2 mm; red marks the arms and the teeth.

Two vertical slices of the two-sided puller at y = 45 mm, before left and after right, the top face up. Left: the defaults with plug sides set to Flat sides, the plug in teal in the cut. Right: grip bite at -2 mm. Marked in red: 1, the arms: the two toothed arms in the upper half. 2, the teeth and the arms: the serrated inner edges of the arms; the two toothed arms in the upper half.

Before: -1. After: -2. Context: `plug_sides` = Flat sides. Section at y = 45 mm. Moves: arms, teeth.

`plate_cradle_depth`: Cradle depth

Cradle depth: before and after, 2.5 to 0 mm; red marks the arms and the teeth.

Two vertical slices of the two-sided puller at y = 45 mm, before left and after right, the top face up. Left: the defaults with plug sides set to Rounded sides, the plug in teal in the cut. Right: cradle depth at 0 mm. Marked in red: 1, the arms: the two toothed arms in the upper half. 2, the teeth and the arms: the serrated inner edges of the arms; the two toothed arms in the upper half.

Before: 2.5. After: 0. Context: `plug_sides` = Rounded sides. Section at y = 45 mm. Moves: arms, teeth.

`plate_grip_clearance`: Grip clearance

Grip clearance: before and after, 0.5 to 2 mm; red marks the arms and the teeth.

Two vertical slices of the two-sided puller at y = 45 mm, before left and after right, the top face up. Left: the defaults with plug sides set to Rounded sides, the plug in teal in the cut. Right: grip clearance at 2 mm. Marked in red: 1, the teeth and the arms: the serrated inner edges of the arms; the two toothed arms in the upper half. 2, the arms: the two toothed arms in the upper half.

Before: 0.5. After: 2. Context: `plug_sides` = Rounded sides. Section at y = 45 mm. Moves: arms, teeth.

`plate_cable_clearance`: Cord channel clearance

Cord channel clearance: before and after, 0.8 to 3 mm; red marks the arms, the cord channel, the finger lobes and the zip stations.

Two top views of one plate of the two-sided puller, before left and after right, the plug end at the top. Left: the defaults, a 20 mm wide plug in teal. Right: cord channel clearance at 3 mm. Marked in red: 1, the finger lobes and the cord channel: the two rounded lobes in the lower half; the gap between the lobes at the bottom. 2, the finger lobes: the two rounded lobes in the lower half. 3, the zip stations: the three small holes along each arm.

Before: 0.8. After: 3. Moves: arms, cord channel, finger lobes, zip stations.

`plate_finger_fit`: Finger hole fit

Finger hole fit: before and after, 1 to 4 mm; red marks the arms, the finger lobes and the zip stations.

Two top views of one plate of the two-sided puller, before left and after right, the plug end at the top. Left: the defaults, a 20 mm wide plug in teal. Right: finger hole fit at 4 mm. Marked in red: 1, the zip stations: the three small holes along each arm. 2, the finger lobes and the arms: the two rounded lobes in the lower half; the two toothed arms in the upper half. 3, the finger lobes: the two rounded lobes in the lower half.

Before: 1. After: 4. Moves: arms, finger lobes, zip stations.

`plate_finger_wall`: Finger lobe wall

Finger lobe wall: before and after, 5 to 9 mm; red marks the arms, the finger lobes and the zip stations.

Two top views of one plate of the two-sided puller, before left and after right, the plug end at the top. Left: the defaults, a 20 mm wide plug in teal. Right: finger lobe wall at 9 mm. Marked in red: 1, the zip stations: the three small holes along each arm. 2, the finger lobes and the arms: the two rounded lobes in the lower half; the two toothed arms in the upper half. 3, the finger lobes: the two rounded lobes in the lower half.

Before: 5. After: 9. Moves: arms, finger lobes, zip stations.

`plate_finger_inner_wall`: Wall beside the cord channel

Wall beside the cord channel: before and after, 3 to 6 mm; red marks the arms, the finger lobes and the zip stations.

Two top views of one plate of the two-sided puller, before left and after right, the plug end at the top. Left: the defaults, a 20 mm wide plug in teal. Right: wall beside the cord channel at 6 mm. Marked in red: 1, the finger lobes: the two rounded lobes in the lower half. 2, the finger lobes and the arms: the two rounded lobes in the lower half; the two toothed arms in the upper half.

Before: 3. After: 6. Moves: arms, finger lobes, zip stations.

`plate_tooth_diameter`: Tooth size

Tooth size: before and after, 2 to 4 mm; red marks the teeth.

Two top views of one plate of the two-sided puller, before left and after right, the plug end at the top. Left: the defaults, a 20 mm wide plug in teal. Right: tooth size at 4 mm: cuts bigger or smaller scallops into the arms' gripping edges. Marked in red: 1, the teeth: the serrated inner edges of the arms. The plate edge, the arms, the finger lobes and the cord channel stay where they were.

Before: 2. After: 4. Moves: teeth.

`plate_tooth_pitch`: Tooth spacing

Tooth spacing: before and after, 2.8 to 4.5 mm; red marks the teeth.

Two top views of one plate of the two-sided puller, before left and after right, the plug end at the top. Left: the defaults, a 20 mm wide plug in teal. Right: tooth spacing at 4.5 mm: spaces the teeth farther apart or closer together along the gripping edges. Marked in red: 1, the teeth: the serrated inner edges of the arms. The plate edge, the arms, the finger lobes and the cord channel stay where they were.

Before: 2.8. After: 4.5. Moves: teeth.

`plate_tooth_depth`: Tooth depth

Tooth depth: before and after, 1 to 0.3 mm; red marks the teeth.

Two top views of one plate of the two-sided puller, before left and after right, the plug end at the top. Left: the defaults, a 20 mm wide plug in teal. Right: tooth depth at 0.3 mm: cuts each tooth deeper or shallower into the gripping edge. Marked in red: 1, the teeth: the serrated inner edges of the arms. The plate edge, the arms, the finger lobes and the cord channel stay where they were.

Before: 1. After: 0.3. Moves: teeth.

`plate_grip_zone_start`: Toothed zone start

Toothed zone start: before and after, 4 to 15 mm; red marks the arms, the teeth and the zip stations.

Two top views of one plate of the two-sided puller, before left and after right, the plug end at the top. Left: the defaults, a 20 mm wide plug in teal. Right: toothed zone start at 15 mm. Marked in red: 1, the zip stations: the three small holes along each arm. 2, the teeth and the arms: the serrated inner edges of the arms; the two toothed arms in the upper half.

Before: 4. After: 15. Moves: arms, teeth, zip stations.

`plate_grip_zone_length`: Toothed zone length

Toothed zone length: before and after, 0 to 12 mm; red marks the arms and the zip stations.

Two top views of one plate of the two-sided puller, before left and after right, the plug end at the top. Left: the defaults, a 20 mm wide plug in teal. Right: toothed zone length at 12 mm: sets how far the teeth run along each arm instead of covering the whole plug body. Marked in red: 1, the zip stations: the three small holes along each arm. 2, the arms: the two toothed arms in the upper half.

Before: 0. After: 12. Moves: arms, zip stations.

`plate_tip_flare`: Tip flare

Tip flare: before and after, 0.7 to 3 mm; red marks the arms, the cord channel, the finger lobes and the zip stations.

Two top views of one plate of the two-sided puller, before left and after right, the plug end at the top. Left: the defaults, a 20 mm wide plug in teal. Right: tip flare at 3 mm: opens the gap wider right at the arm tips so the plug head can enter before the teeth bite. Marked in red: 1, the arms: the two toothed arms in the upper half. 2, the zip stations: the three small holes along each arm.

Before: 0.7. After: 3. Moves: arms, cord channel, finger lobes, zip stations.

`plate_arm_tip_width`: Arm tip width

Arm tip width: before and after, 11 to 16 mm; red marks the arms and the zip stations.

Two top views of one plate of the two-sided puller, before left and after right, the plug end at the top. Left: the defaults, a 20 mm wide plug in teal. Right: arm tip width at 16 mm: widens the rounded tip of each arm, so the arms taper less. Marked in red: 1, the arms: the two toothed arms in the upper half. 2, the zip stations: the three small holes along each arm.

Before: 11. After: 16. Moves: arms, zip stations.

`plate_edge_rounding`: Outer edge rounding

Outer edge rounding: before and after, 1.2 to 0 mm; red marks the finger lobes.

Two vertical slices of the two-sided puller at y = 3 mm, before left and after right, the top face up. Left: the defaults, the plug in teal in the cut. Right: outer edge rounding at 0 mm: rounds or squares the outer face's edge all around the plate, while the plug-contact face stays square. Marked in red: 1, the finger lobes: the two rounded lobes in the lower half. The plate edge, the arms, the teeth and the cord channel stay where they were.

Before: 1.2. After: 0. Section at y = 3 mm. Moves: finger lobes.

`plate_strip_thickness`: Cable strip thickness

Cable strip thickness: before and after, 1 to 0 mm; red marks the cord channel.

Two vertical slices of the two-sided puller at y = 3 mm, before left and after right, the top face up. Left: the defaults, the plug in teal in the cut. Right: cable strip thickness at 0 mm: thickens or removes the thin strip that bridges the cord channel on the outer face and ties the two arms together. Marked in red: 1, the cord channel: the gap between the lobes at the bottom. The plate edge, the arms, the teeth and the finger lobes stay where they were.

Before: 1. After: 0. Section at y = 3 mm. Moves: cord channel.

`plate_zip_hole_diameter`: Zip-tie hole diameter

Zip-tie hole diameter: before and after, 4 to 6 mm; red marks the arms, the finger lobes, the strap slot and the zip stations.

Two top views of one plate of the two-sided puller, before left and after right, the plug end at the top. Left: the defaults, a 20 mm wide plug in teal. Right: zip-tie hole diameter at 6 mm. Marked in red: 1, the zip stations and the arms. 2, the zip stations, the finger lobes and the arms. 3, the zip stations and the strap slot.

Before: 4. After: 6. Moves: arms, finger lobes, strap slot, zip stations.

`plate_zip_placement`: Zip-tie station placement

Zip-tie station placement: before and after, Auto to Manual; red marks the arms, the strap slot and the zip stations.

Two top views of one plate of the two-sided puller, before left and after right, the plug end at the top. Left: the defaults with plug length set to 40, a 20 mm wide plug in teal. Right: zip-tie station placement set to Manual. Marked in red: 1, the arms: the two toothed arms in the upper half. 2, the zip stations: the three small holes along each arm. 3, the strap slot: the long slot in each arm.

Before: Auto. After: Manual. Context: `measure_plug_length` = 40. Moves: arms, strap slot, zip stations.

`plate_zip_pos_1`: Zip-tie station 1 position

Zip-tie station 1 position: before and after, 4 to 27 mm; red marks the zip stations.

Two top views of one plate of the two-sided puller, before left and after right, the plug end at the top. Left: the defaults with plug length set to 40 and zip-tie station placement set to Manual, a 20 mm wide plug in teal. Right: zip-tie station 1 position at 27 mm: slides the rear zip-tie station along each arm, measured from the cord end. Marked in red: 1, the zip stations: the three small holes along each arm.

Before: 4. After: 27. Context: `measure_plug_length` = 40, `plate_zip_placement` = Manual. Moves: zip stations.

`plate_zip_pos_2`: Zip-tie station 2 position

Zip-tie station 2 position: before and after, 32 to 36 mm; red marks the strap slot and the zip stations.

Two top views of one plate of the two-sided puller, before left and after right, the plug end at the top. Left: the defaults with plug length set to 40 and zip-tie station placement set to Manual, a 20 mm wide plug in teal. Right: zip-tie station 2 position at 36 mm. Marked in red: 1, the zip stations and the strap slot: the three small holes along each arm; the long slot in each arm.

Before: 32. After: 36. Context: `measure_plug_length` = 40, `plate_zip_placement` = Manual. Moves: strap slot, zip stations.

`plate_zip_pos_3`: Zip-tie station 3 position

Zip-tie station 3 position: before and after, 63 to 58 mm; red marks the arms, the strap slot and the zip stations.

Two top views of one plate of the two-sided puller, before left and after right, the plug end at the top. Left: the defaults with plug length set to 40 and zip-tie station placement set to Manual, a 20 mm wide plug in teal. Right: zip-tie station 3 position at 58 mm. Marked in red: 1, the arms: the two toothed arms in the upper half. 2, the zip stations: the three small holes along each arm, removed. 3, the zip stations and the strap slot.

Before: 63. After: 58. Context: `measure_plug_length` = 40, `plate_zip_placement` = Manual. Moves: arms, strap slot, zip stations.

`plate_slot_inner_wall`: Wall between the teeth and the slot

Wall between the teeth and the slot: before and after, 2.2 to 5 mm; red marks the arms, the strap slot and the zip stations.

Two top views of one plate of the two-sided puller, before left and after right, the plug end at the top. Left: the defaults with plug length set to 40, a 20 mm wide plug in teal. Right: wall between the teeth and the slot at 5 mm. Marked in red: 1, the zip stations: the three small holes along each arm. 2, the strap slot and the arms: the long slot in each arm; the two toothed arms in the upper half.

Before: 2.2. After: 5. Context: `measure_plug_length` = 40. Moves: arms, strap slot, zip stations.

`plate_velcro_slot_width`: Strap slot width

Strap slot width: before and after, 9.3 to 14 mm; red marks the arms, the strap slot and the zip stations.

Two top views of one plate of the two-sided puller, before left and after right, the plug end at the top. Left: the defaults with plug length set to 40, a 20 mm wide plug in teal. Right: strap slot width at 14 mm. Marked in red: 1, the zip stations: the three small holes along each arm. 2, the strap slot and the arms: the long slot in each arm; the two toothed arms in the upper half.

Before: 9.3. After: 14. Context: `measure_plug_length` = 40. Moves: arms, strap slot, zip stations.

`plate_velcro_slot_length`: Strap slot length

Strap slot length: before and after, 28 to 15 mm; red marks the arms, the strap slot and the zip stations.

Two top views of one plate of the two-sided puller, before left and after right, the plug end at the top. Left: the defaults with plug length set to 40, a 20 mm wide plug in teal. Right: strap slot length at 15 mm: lengthens or shortens the strap slot along each arm, within the window between the zip-tie stations. Marked in red: 1, the strap slot: the long slot in each arm. 2, the arms: the two toothed arms in the upper half.

Before: 28. After: 15. Context: `measure_plug_length` = 40. Moves: arms, strap slot, zip stations.

### Advanced - Render Quality

`quality`: Render quality

Render quality: changes no shape.

This dial changes no shape: it only sets the number of segments in every circle and arc.

This dial changes no shape. Changes no shape: it only sets the number of segments in every circle and arc.

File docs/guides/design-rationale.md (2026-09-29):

# Design rationale

Every default in the two files has a reason. This page gives each one in the same shape: the decision, the number, the evidence, and what happens if you change it. The numbers come from the files named beside them.

---

## The 24 mm split between the two tools

**The decision.** A plug up to 24 mm thick gets the one-sided puller; a thicker plug gets the two-sided puller.

**The number.** 24 mm, from `docs/Plug_Puller_Reference.md` section 1 and the W-20 check in `src/Plug_Puller_Parametric.scad`.

**The evidence.** The one-sided puller holds the plug in a pocket cut into a slab 6.35 mm thick at Medium (`README.md`, Sizes); the pocket's side walls and the zip ties do the holding, from one side only. The two-sided plates close across the plug from both sides, so the plug's thickness sets their gap instead of limiting them. The reference states the 24 mm rule and the tag; it does not state how the number was chosen, and this page does not guess.

**What you may change.** Nothing here is a dial. If you type a thickness of 24 mm or more into the one-sided file it prints the red tag `PLUG THICKER THAN 24MM - USE THE TWO-SIDED PULLER FILE` beside the part and the part is still built, so you can see it, but it will not hold that plug.

---

## Three sizes from measured hands

**The decision.** `Small`, `Medium` and `Large` are hand sizes, not tool sizes: each sets a finger width and a hand width, and the finger holes and the body follow.

**The numbers.** Finger and hand width: Small 16.5 and 72 mm, Medium 20 and 85 mm, Large 23 and 96 mm, in `src/fit_sizes.scad`. The finger holes come out at 17.5, 21 and 24 mm across in the two-sided puller (`docs/Plug_Puller_Reference.md` section 2).

**The evidence.** The pairs come from the ANSUR II (2012) hand breadth survey and Rogers (2008) knuckle breadth, as `README.md` (Sizes) states: Small is about a 5th-percentile female hand, Large about a 95th-percentile male hand, and Medium is the reference device the owner printed and tested. The reference does not state the exact percentile behind each number beyond that.

**What you may change.** `Measure my hand` replaces the pair with your own two numbers and everything follows. A finger hole is sized to the knuckle, so a hole that is too tight pinches and one that is too loose lets the finger slip: measure at the widest knuckle, as the [quick start](one-sided/quick-start.md) shows.

---

## The two-sided cradle and the bite

**The decision.** The two-sided plates grip a plug in one of two ways: `Rounded sides` cuts a sloped cradle into each arm; `Flat sides` keeps the arms straight and squeezes.

**The numbers.** `plate_cradle_depth` 2.5 mm per side and `plate_grip_clearance` 0.5 mm for `Rounded sides`; `plate_grip_bite` of minus 1 mm for `Flat sides` and the presets. All three are dials in `src/Plug_Puller_Two_Sided.scad`; the geometry is in `docs/Plug_Puller_Reference.md` section 6.1.

**The evidence.** Stacked, the two cradles form a diamond-shaped channel that is widest where the plates meet and 2.5 mm narrower per side at the outer faces, so a round or oval plug rests on four sloped faces and centers itself; the half millimeter of clearance lets a hard plug drop in flat and forgives a small measuring error. A boxy plug has no curve to center on, so the arms stay straight and close 1 mm tighter than the plug on each side: the teeth bite and the plates cannot slide.

**What you may change.** A deeper cradle is steeper; the file will not let it go below the cord channel's width and says so with the tag `CRADLE SHALLOWER THAN ASKED - PLUG NARROW`. A bite of zero or more means the arms never squeeze a flat-sided plug, and the tag `NO GRIP BITE - PLUG WONT BE HELD` appears.

---

## PETG

**The decision.** PETG is the recommended filament; PLA, ABS and ASA work; flexible filament does not.

**The evidence.** `README.md` (3D printing tips) and `docs/makerworld-listing.md` (print settings): the cord hook and the finger holes flex a little on every pull, and PETG takes that repeated flexing without cracking where PLA can; it also shrugs off the warmth near a misbehaving outlet. A flexible filament bends instead of pulling.

**What you may change.** The material is your slicer's choice, not the file's. Whatever you print in, 3 to 4 walls keep the hook and the zip-tie holes strong (the [full guide](one-sided/full-guide.md) names a snapped hook as the sign of too few walls).

---

## Red tags as error messages you can hold

**The decision.** When a number cannot work, the file does not stop: it builds the part and lays red text beside it that names the measurement to fix, as real geometry.

**The evidence.** `docs/Plug_Puller_Reference.md` section 10 lists the twenty one-sided checks (W-1 to W-20) and the thirteen two-sided checks (WC-1 to WC-13). The tag is geometry because the customizer on MakerWorld shows only the finished model: a message that lived only in a text pane would be invisible there. A red coupon in the preview, and on the bed if you export anyway, cannot be missed by anyone.

**What you may change.** Nothing turns the tags off. Fix the number and the tag goes away; the [full guide](one-sided/full-guide.md) decodes every one.

---

## The see-through plug in the preview

**The decision.** Both files draw a translucent plug in the pocket or between the arms while you customize, and leave it out of the export.

**The evidence.** `docs/Plug_Puller_Reference.md` sections 5.5 and 10: the plug is drawn from your numbers, so if it looks wrong on the screen, the numbers are wrong. It never reaches the STL.

**What you may change.** `show_plug_preview` turns it off; nothing else changes.

---

## Measured presets only

**The decision.** A plug preset exists only for a plug the owner measured at two stations, the prong end and the cord end; there are no presets typed from a catalog.

**The evidence.** `docs/Plug_Puller_Reference.md` section 2.1: only the prongs of a plug are standardized, not the body, so two plugs that fit the same outlet can differ by millimeters in every dimension that matters here. Each preset carries the length, both widths, both thicknesses and the cord of one measured plug, taken just behind the prongs and where the cord leaves the body.

**What you may change.** `Measure my plug` with your own six numbers is always the safer choice for a plug that is not on the list; the outline sheets and the stencil cards let you check before you print.

---
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

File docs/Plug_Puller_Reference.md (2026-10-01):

# Plug Puller — Complete Object Reference

> **Covers**: two tools in two files — the one-sided puller and the
> two-sided puller
> **Files**: `src/Plug_Puller_Parametric.scad`, the one-sided puller
> (`include`s `src/fit_sizes.scad`, `src/fit_measured.scad`, then
> `src/presets.scad` — order matters, see [Section 8.4](#84-include-order));
> `src/Plug_Puller_Two_Sided.scad`, the two-sided puller (`include`s
> `src/fit_sizes.scad`)
> **Entry points**: open either file in OpenSCAD; the single-file builds
> are `dist/Plug_Puller_SingleFile.scad` and
> `dist/Plug_Puller_Two_Sided_SingleFile.scad`
> **One-sided heritage**: the v6.0 CAD model "Plug Puller 3.1 - B", measured during development (not part of this repository)
> **Two-sided reference**: `plug references/3 Prong Heavy Ideal Sample/…Plug_Bottom.stl`
> **Last Updated**: 2026-09-24
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

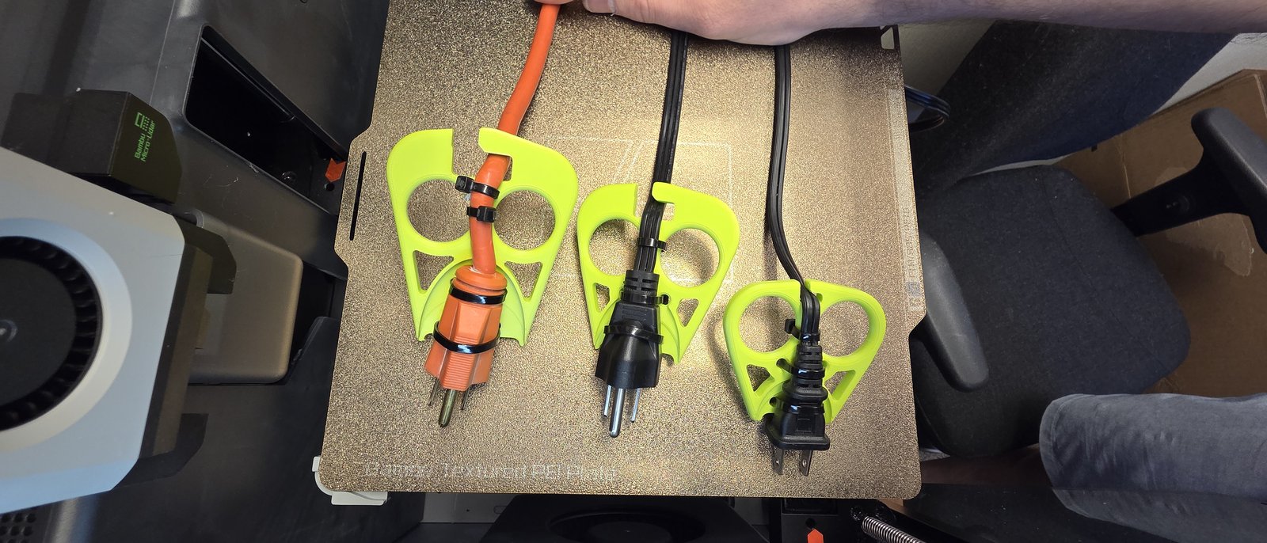
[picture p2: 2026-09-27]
docs/images/one-sided-three-sizes.jpg

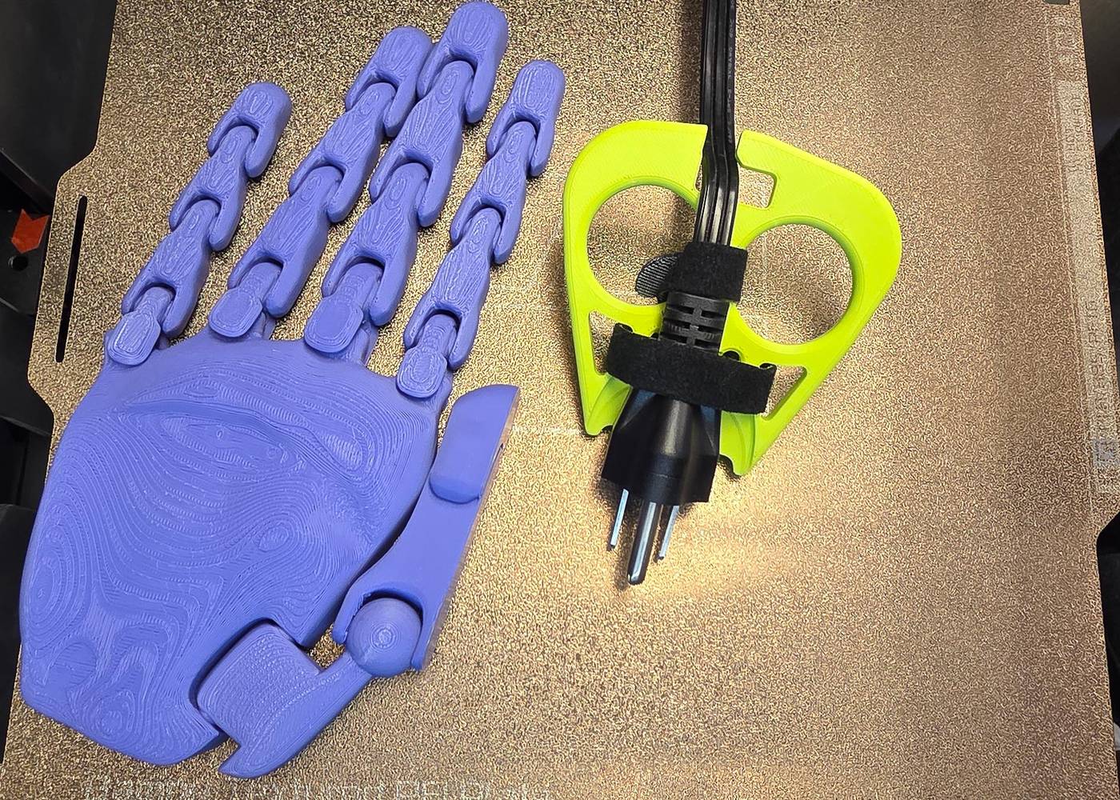
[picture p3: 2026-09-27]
docs/images/one-sided-3-prong-plug-large.jpg

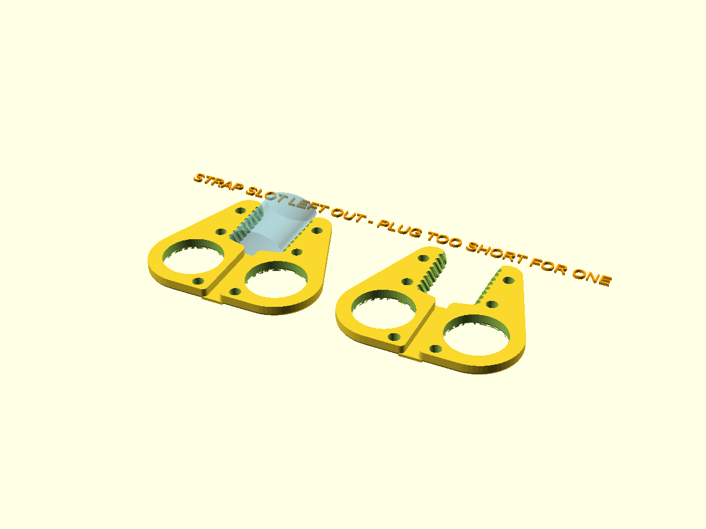
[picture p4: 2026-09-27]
docs/images/two-sided-plate-render.png

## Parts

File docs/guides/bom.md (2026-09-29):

# Bill of materials

Nothing to solder and almost nothing to buy: filament, zip ties, and a strap if you want one. The measuring stencil is printed, not bought.

| Item | How many | Size | Where it goes |
| ---- | --- | ---- | --- |
| Zip ties, one-sided puller | 2 per tool | up to 4.8 mm wide, about 200 mm long | the zip-tie holes beside the pocket, 5.08 mm across |
| Zip ties, two-sided puller | 3 per pair of plates | up to 3.6 mm wide, about 200 mm long | the zip-tie stations, 4 mm across |
| Hook-and-loop strap | 1 per tool, optional | 10, 13, 16, 20 or 25 mm wide | the two wing openings of the one-sided puller |
| Filament | see the table below | PETG, or PLA | the tool |
| A printer | 1 | a bed of 200 by 200 mm or larger for the stencil sheets | the tool, the stencil cards |
| Measuring stencil | 1 set | printed from `stl/Measuring-Stencil/` | matching a plug and sizing a finger |

About the strap: ONE-WRAP ties come in 10, 13, 16, 20 and 25 mm widths. Set the `strap_width` dial to the width you bought; its default of 15 mm is not a ONE-WRAP size, so change it. A narrower bed still prints the stencil one card at a time.

## Filament per tool

The numbers below are upper bounds: they are the solid volume of each shipped STL (from `stl/Plug-Puller/`, measured with trimesh) times 1.27 g per cubic centimeter for PETG. A print at 25 to 35 percent infill uses less. A two-sided file holds both plates.

| Tool and plug | Small  | Medium | Large  |
| --- | --- | --- | --- |
| One-sided, flat 2-prong lamp plug | 12.0 g | 17.0 g | 21.2 g |
| One-sided, standard 3-prong plug | 16.7 g | 23.8 g | 30.1 g |
| One-sided, wide 2-prong appliance plug | 15.2 g | 21.3 g | 26.8 g |
| Two-sided, heavy-duty extension cord (both plates) | 15.0 g | 17.1 g | 19.0 g |
| Two-sided, USB-C laptop tip (both plates) | 13.0 g | 14.8 g | 16.4 g |
| Two-sided, flat 2-prong lamp plug (both plates) | 15.4 g | 17.5 g | 19.4 g |
| Two-sided, standard 3-prong plug (both plates) | 17.4 g | 19.6 g | 21.8 g |

The solid volumes behind these grams: one-sided lamp 9.48, 13.36 and 16.66 cubic centimeters; one-sided standard 13.13, 18.70 and 23.69; one-sided wide appliance 11.99, 16.81 and 21.11; two-sided heavy-duty cord 11.83, 13.49 and 14.94; two-sided USB-C 10.21, 11.66 and 12.94; two-sided lamp 12.12, 13.82 and 15.30; two-sided standard 13.69, 15.41 and 17.13. A custom tool lands near the preset closest to its plug. For PLA multiply the grams by 0.98.

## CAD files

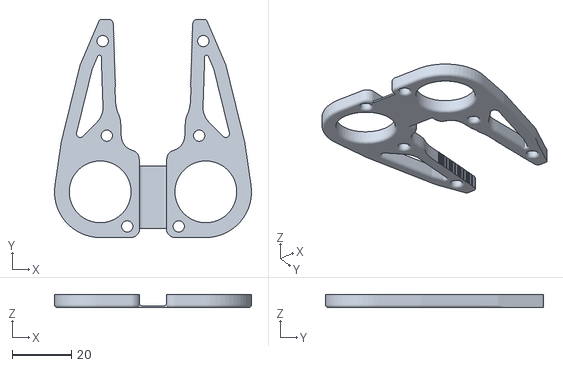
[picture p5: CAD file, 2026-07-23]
plug references/3 Prong Heavy Ideal Sample/Plug Puller_3_Prong_Idealized_Sample_Plug_Bottom.stl
66.6 x 73.7 x 4.50

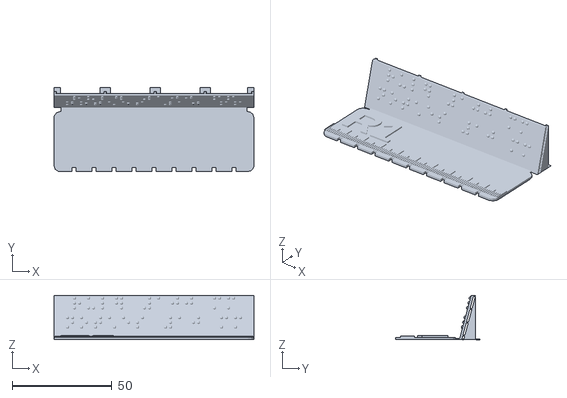
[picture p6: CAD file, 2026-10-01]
stl/Measuring-Stencil/Tactile/Measuring-Stencil_Tactile_R1_Ruler-100mm.stl
100.0 x 42.2 x 22.2

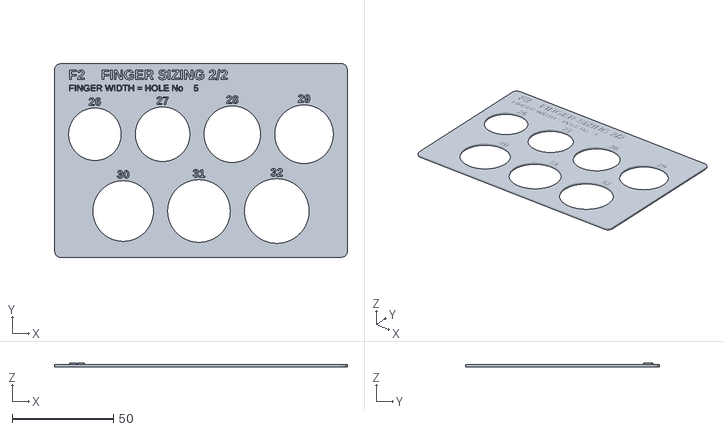
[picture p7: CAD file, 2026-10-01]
stl/Measuring-Stencil/Visual/Measuring-Stencil_Visual_F2_Finger-Sizing-26-32mm.stl
145.0 x 96.0 x 2.00

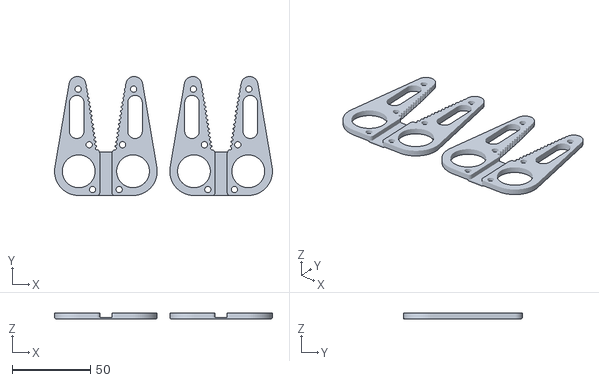
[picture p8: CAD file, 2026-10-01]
stl/Plug-Puller/Plug-Puller_Two-Sided_Standard-3-Prong-NEMA-5-15_Medium.stl
139.6 x 76.2 x 4.00

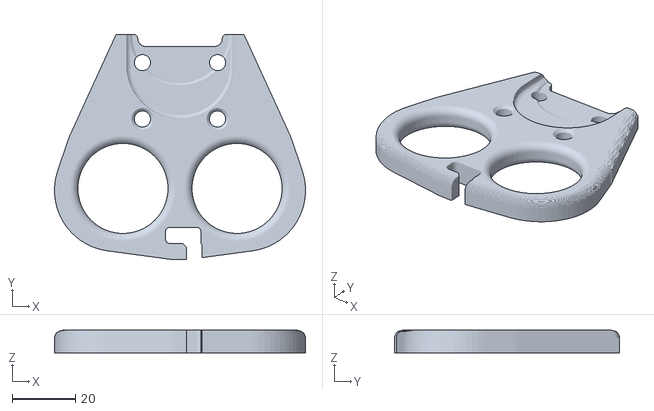
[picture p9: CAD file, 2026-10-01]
tests/fixtures/large/reference.stl
79.2 x 71.1 x 7.15

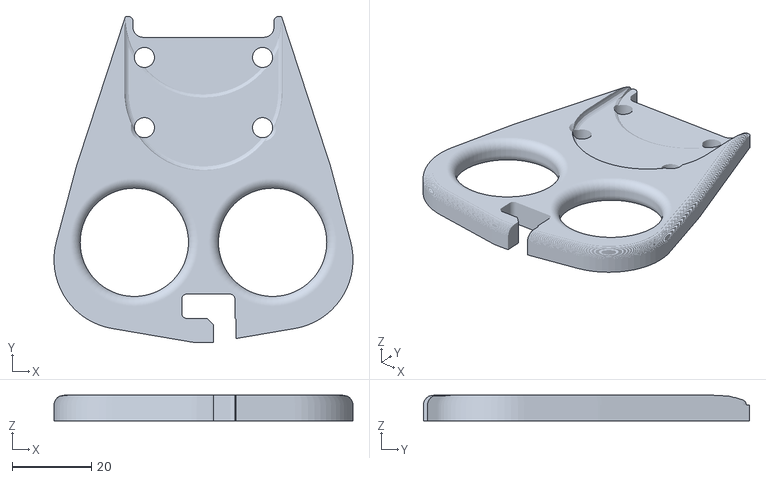
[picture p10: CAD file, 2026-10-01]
tests/fixtures/measured_hand/reference.stl
75.7 x 82.6 x 6.55

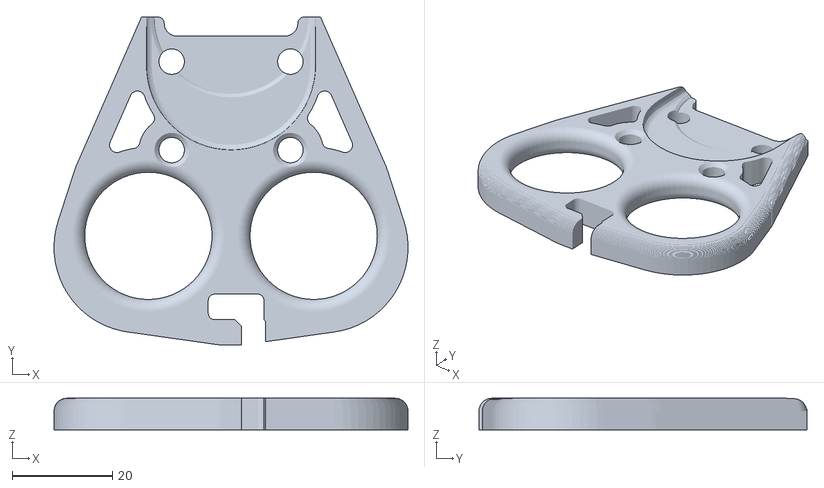
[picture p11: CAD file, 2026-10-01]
tests/fixtures/medium/reference.stl
70.7 x 65.5 x 6.35

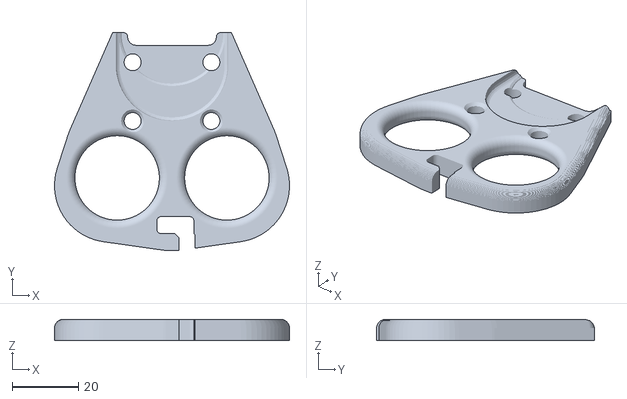
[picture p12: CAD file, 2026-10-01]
tests/fixtures/medium_body_only/reference.stl
70.7 x 65.5 x 6.35

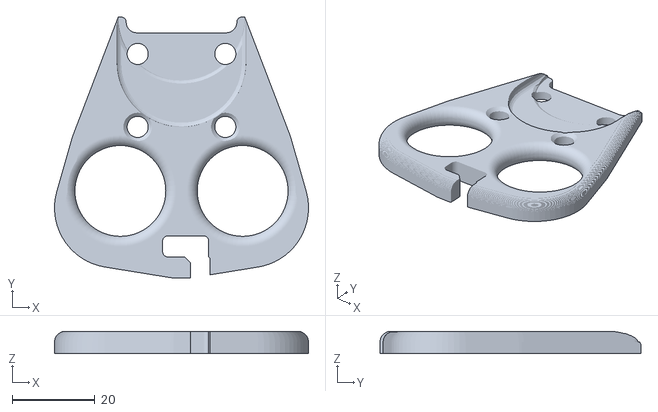
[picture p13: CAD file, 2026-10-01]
tests/fixtures/small/reference.stl
61.3 x 63.0 x 5.40

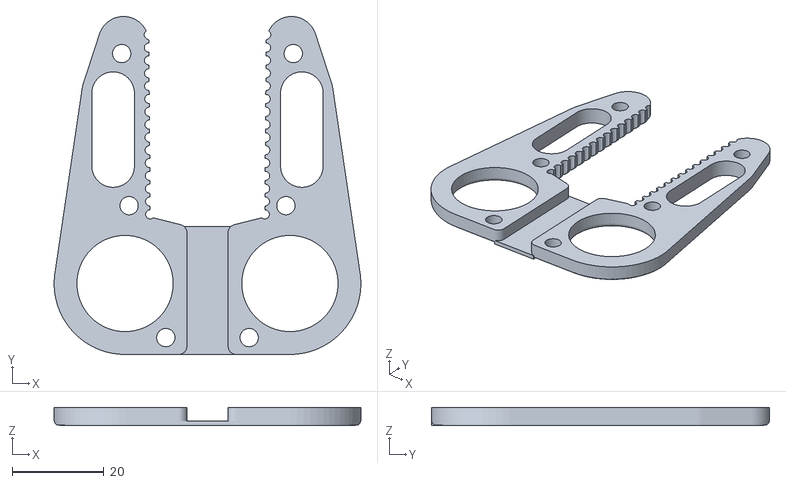
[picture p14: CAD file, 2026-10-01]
tests/fixtures/two_sided_plate/reference.stl
67.0 x 73.8 x 4.00

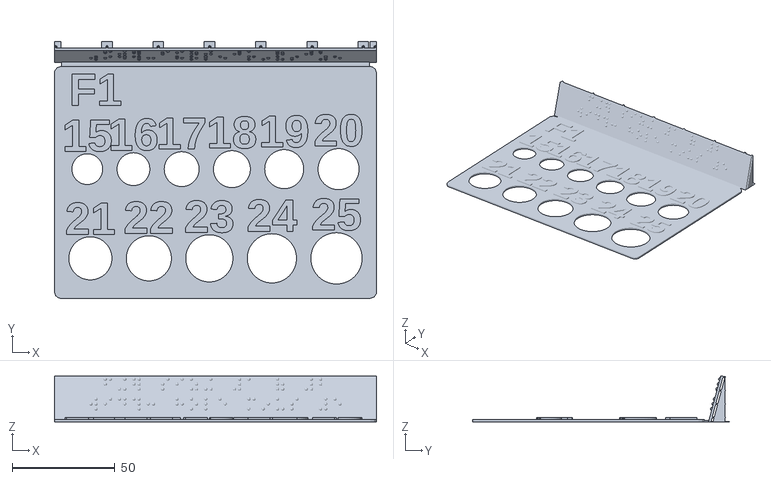
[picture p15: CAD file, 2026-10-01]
stl/Measuring-Stencil/Tactile/Measuring-Stencil_Tactile_F1_Finger-Sizing-15-25mm.stl
157.0 x 125.2 x 22.2

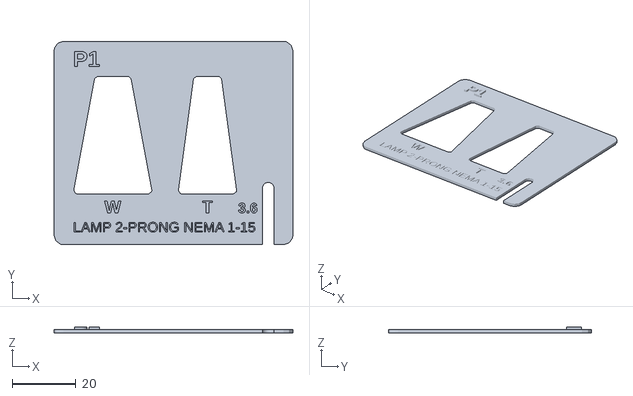
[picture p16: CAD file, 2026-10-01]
stl/Measuring-Stencil/Visual/Measuring-Stencil_Visual_P1_Lamp-Plug-Gauge.stl
75.2 x 64.0 x 2.00

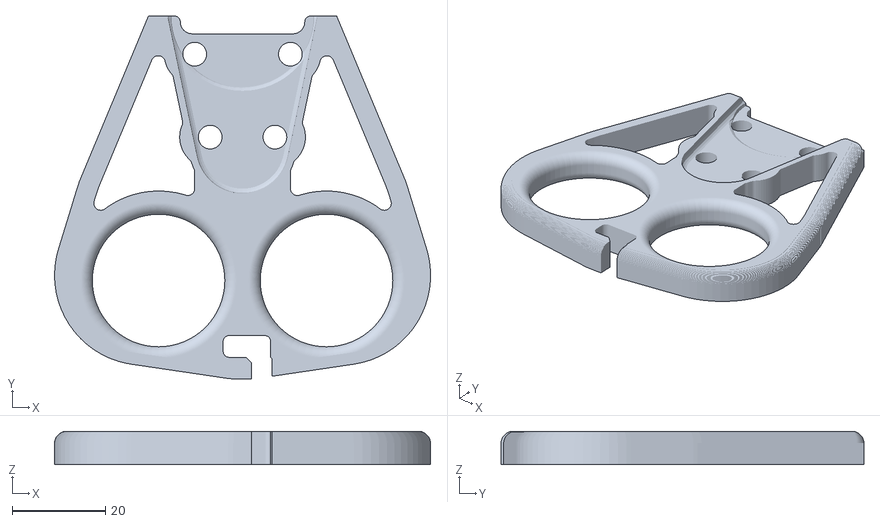
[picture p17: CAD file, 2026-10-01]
stl/Plug-Puller/Plug-Puller_Flat-2-Prong-Lamp-NEMA-1-15_Large.stl
80.6 x 77.8 x 7.15

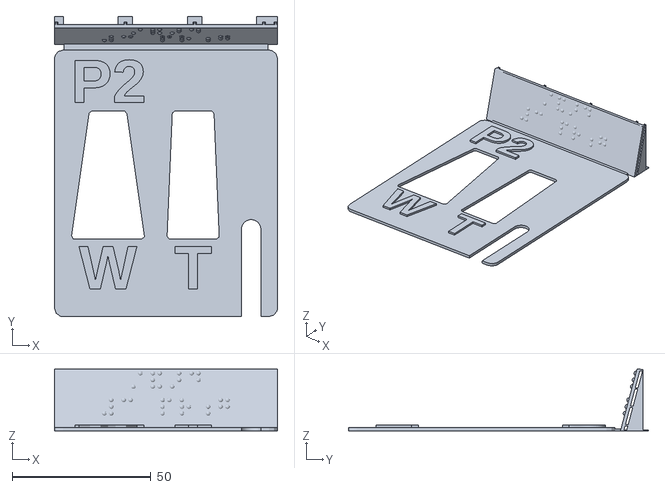
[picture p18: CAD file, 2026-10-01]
stl/Measuring-Stencil/Tactile/Measuring-Stencil_Tactile_P2_Standard-3-Prong-Gauge.stl
80.5 x 108.4 x 22.2

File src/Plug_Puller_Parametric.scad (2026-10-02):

// Plug Puller 0.14.0 — Parametric Generator for the one-sided puller
// The one-sided puller is the reworked v6 flat puller: a slab with a
// two-level plug pocket whose side walls follow a parametric "plug side
// rail", plus rail-placed zip-tie holes and velcro slots, finger bores, and a
// chiral J-hook cord catch. Its Medium defaults descend from the v6 Plug
// Puller ("Plug Puller 3.1 - B") but are no longer a sub-mm mesh clone.
// The two-sided puller (two plates that zip-tie around a plug) is its own file: src/Plug_Puller_Two_Sided.scad.
//
// ── Quick Start (the numbered Steps are all a beginner needs) ───────────────
//   1. Open this file in OpenSCAD (v2021.01 or later recommended)
//   2. Show the Customizer panel: View ▸ Hide Customizer — make sure it is
//      UNCHECKED (older builds: Window ▸ Customizer)
//   3. Fill in the numbered Steps top to bottom:
//        Step 1: Your plug — pick a plug preset, or measure your plug
//                (docs/guides/one-sided/quick-start.md shows every
//                measurement).
//        Step 2: Size — Medium is the reference; Small / Large for other
//                hands; "Measure my hand" to type two hand numbers.
//        Step 3: Attachment — how the tool straps onto the plug.
//        Step 4: Cord hook — right- or left-handed cord catch.
//   4. Press F6 to render, then File ▸ Export ▸ STL to save your print file
//
//   The Customizer is organized in three tiers:
//     "Step 1" … "Step 4"       the guided path — beginners stop here
//     "Advanced - …" sections   power dials: manual zip/velcro placement and
//                               render quality
//                               (see docs/guides/one-sided/full-guide.md)
//     "… (Custom size only)"    expert geometry sliders, active only when
//                               Size = Custom (all measurements are ignored)
// ─────────────────────────────────────────────────────────────────────────────
//
// Coordinate frame:
//   X = 0 at horizontal midline (symmetric)
//   Y = 0 at cord/T-hook end (narrow end), positive toward plug end
//   Z = 0 at print bed, positive upward
//
// Plug side rail (the "few dials, max agency" concept):
//   A 2D line describing the plug's side edge inside the tool, defined by the
//   pocket half-width at the plug face and one `pocket_side_angle` taper.
//   Zip stations and velcro slots are positioned as (t, d) = (mm along the
//   rail from the plug face,
//   mm outward-normal offset) so one slider slides a feature coherently along
//   the plug's side. See rail_point()/rail_feature_center() below.
//
// Architecture:
//   1. Body slab: octagonal control polygon; when `body_round_bottom_only`
//      is set, the cord half is opened (offset-rounded) into the organic
//      blob of the original while the plug end stays crisp
//   2. Plug pocket: a taper-aware recess (side walls follow the plug rail,
//      rounded nose) plus a deeper circular seat disc centered on the top
//      edge (partial-depth cuts; no fill pieces needed)
//   3. Subtract feature cutouts (holes, notches, slots)

// ═══════════════════════════════════════════════════════════════════════════════
// CUSTOMIZER PARAMETERS
// ═══════════════════════════════════════════════════════════════════════════════
// UI tiers (file order = Customizer order):
//   Steps 1-4                    the guided beginner path
//   "Advanced - …"               power dials for experienced users
//   [Hidden]                     programmatic switches, not shown in the UI
//   "… (Custom size only)"       expert sliders, active only in Size = Custom

// MAINTAINER NOTE: dropdown option labels must not contain parentheses — the
// OpenSCAD Customizer fails to parse such enum values and silently reverts
// the selection to the default (MakerWorld PMM inherits this behaviour).

/* [Step 1 - Your Plug] */
// The fastest start: pick your plug from this list and every measurement below fills in automatically. Pick "Measure my plug" to type your own numbers instead - the quick start, docs/guides/one-sided/quick-start.md, walks you through each one in about 5 minutes.
plug_preset = "Measure my plug"; // [Measure my plug, Flat 2-prong lamp plug - NEMA 1-15, Standard 3-prong plug - NEMA 5-15, Heavy-duty extension cord - NEMA 5-15, Wide 2-prong appliance plug - NEMA 1-15]
// How far the plug body sticks out, from the surface it plugs into to the plug's back end where the cord starts. On a wall outlet, measure from the wall plate; on a laptop or charger, from the device's edge. The tool's pocket runs this full length. Skip if you picked a plug preset. (mm)
measure_plug_length = 25.5; // [12:0.5:85]
// Plug width at the PRONG END: straight across the plastic body just behind the prongs (not the metal prongs), the WIDE way, holding the ruler parallel to the wall. On a USB-C or charger tip, just behind the metal tip. Skip if you picked a plug preset. (mm)
measure_plug_width_prong_end = 25; // [8:0.5:38]
// Plug width at the CORD END: the same wide direction, measured where the cord leaves the plug body. Skip the soft rubber strain relief. Together the two widths tell the tool which end of the plug is wider. Skip if you picked a plug preset. (mm)
measure_plug_width_cord_end = 25; // [8:0.5:38]
// Plug thickness at the PRONG END: across the plug's THIN direction (usually top to bottom on a flat plug), just behind the prongs. The thicker end sets how deep the pocket is; a plug 24 mm or thicker needs the two-sided puller file. Skip if you picked a plug preset. (mm)
measure_plug_thickness_prong_end = 20; // [4:0.5:40]
// Plug thickness at the CORD END: the same thin direction, measured where the cord leaves the plug body. Skip the soft rubber strain relief. Skip if you picked a plug preset. (mm)
measure_plug_thickness_cord_end = 20; // [4:0.5:40]
// Measure the cord just behind the plug, across its THIN side (flat lamp cord: the narrow way; round cord: the diameter). Skip if you picked a plug preset. (mm)
measure_cord_thickness = 4; // [1.5:0.5:9]
// Look at your outlet's cover plate: "Standard flat plate" = two small oval openings, "Rocker / Decora" = one big rectangle per outlet. This sets how deep the tool's end notch is so it can sit flat against the wall.
measure_wall_plate_style = "Standard flat plate"; // [Standard flat plate, Rocker / Decora, Oversized / Jumbo, No plate / flush]
// Show a see-through plug built from these numbers in the pocket in the preview so you can check the fit. It is never part of the exported file. MakerWorld shows the finished tool only.
show_plug_preview = true;

/* [Step 2 - Size] */
// Pick the hand size. Medium = the original Plug Puller and fits most adults. Small / Large cover smaller and bigger hands. "Measure my hand" builds the grip from the two numbers below. "Custom" is for experts: it ignores ALL measurements and unlocks every "(Custom size only)" slider further down.
size = "Medium"; // [Small, Medium, Large, Measure my hand, Custom]
// Used only when Size = "Measure my hand". Measure across the WIDEST knuckle of your middle finger - the finger that goes in the pull hole. No caliper? A snugly fitting ring's inner diameter + 1.5 mm works too. (mm)
measure_finger_width = 20; // [14:0.5:32]
// Used only when Size = "Measure my hand". Measure straight across the four knuckles of your flat hand, fingers together, no thumb. (mm)
measure_hand_width = 85; // [60:1:110]

/* [Step 3 - Attachment] */
// How the tool attaches to the plug. Zip ties = the 4-hole grid, Velcro strap = the angled wing slots. The original device uses both, so both is the default.
attachment = "Zip ties + Velcro"; // [Zip ties, Velcro strap, Zip ties + Velcro, None]
// Shape of the velcro strap opening. Wing = the curved openings of the original (bigger opening, less plastic). Classic slot = a simple rectangular slot.
velcro_style = "Wing"; // [Wing, Classic slot]
// Width of the hook-and-loop strap you'll thread through the openings - check the strap's packaging (ONE-WRAP comes in 10/13/16/20/25 mm). The wing opening does not change with this number; it is only compared against the strap, so a wing too narrow for it prints the W-14 tag. (mm)
strap_width = 15; // [10:1:25]

/* [Step 4 - Cord Hook] */
// Which way the tool's cord catch faces. Right = the original device. Pick whichever lets you hook the cord with your preferred hand - the hook is mirrored, nothing else changes.
hook_hand = "Right"; // [Right, Left]
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

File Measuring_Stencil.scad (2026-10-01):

// =============================================================================
// Measuring_Stencil.scad — printable measuring stencil (supersedes the old
// Finger_Sizing_Stencil.scad)
// =============================================================================
//
// A set of thin measuring cards that answer the Plug Puller worksheet without
// a caliper. Each card carries a raised 2-character ID you can read by touch;
// the legend is in both tools' guides, under "Match a card instead of
// measuring" (written once, in docs/guides/source/stencil-cards.md):
//
//   P1 … P4      plug preset cards — hold your plug in the cutouts; if it
//                 fills the W (width) and T (thickness) openings and the cord
//                 slips sideways into the open cord slot, that preset fits —
//                 pick it in Step 1 and skip measuring entirely.
//                   P1 = flat 2-prong lamp plug (NEMA 1-15)
//                   P2 = standard 3-prong plug (NEMA 5-15)
//                   P3 = heavy-duty extension cord (NEMA 5-15)
//                   P4 = wide 2-prong appliance plug (NEMA 1-15)
//   R1            ruler card — raised tactile ticks (1 mm short, 5 mm medium,
//                 10 mm tall), debossed numerals, and touch-countable edge
//                 notches every 10 mm (worksheet measurements 1-5).
//   C1            cord gauge — open-throat U-slots 3-9 mm through the bottom
//                 edge: slide the card sideways onto an installed cord; the
//                 smallest slot that slips over it is the cord diameter
//                 (worksheet measurement 6).
//   F1 / F2       finger sizing — the 18 gauge holes; smallest comfortable
//                 hole minus 5 = your finger width (worksheet measurement 8).
//
// Label modes (ADA 703 naming — by modality, not audience):
//   Visual  = debossed print lettering (ADA 703.5 style, the default).
//   Tactile = raised uppercase characters at ADA 703.2 size (16 mm, 0.8 mm
//             proud) plus a Grade 2 braille title flap on every card
//             (ADA 703.3). Each flap prints leaning back at 75 deg behind
//             the card's top edge — the angle braille prints crispest at —
//             held by break-away support fins. After printing: snap off the
//             fins, then fold the flap AWAY from the card until it lies
//             flat; the braille lands face-up beyond the card's top edge.
//             Fold once, gently — PETG/PP hinges fold more reliably than PLA.
//
// Printing: all cards lie flat, no supports. PETG or PLA, 0.2 mm layers. At
// the default 1.2 mm thickness the full set prints fast. Small printer? Set
// `bed_width` / `bed_depth` to your bed and the cards pack themselves onto
// numbered sheets — render `part_index` = 1, 2, ... to export one sheet at a
// time (0 previews every sheet at once).
//
// License: PolyForm Noncommercial 1.0.0

/* [Stencil] */
// Plate thickness of every card. 1.2 mm is stiff enough and prints fast; go thicker for a sturdier gauge. (mm)
stencil_thickness = 1.2; // [0.6:0.2:3]
// Corner rounding of each card outline. (mm)
corner_radius = 3; // [0:0.5:8]
// How deep the labels are pressed into the top face. Must stay below the plate thickness. (mm)
deboss_depth = 0.6; // [0.2:0.1:1]
// How many segments make up each circle. 64 is print-ready. Higher = smoother but slower.
quality = 64; // [24:8:128]

/* [Labels] */
// Visual = debossed print lettering (ADA 703.5 style). Tactile = raised ADA 703.2 characters plus Grade 2 braille flaps (ADA 703.3).
label_mode = "Visual"; // [Visual, Tactile]
// Living-hinge thickness joining each braille flap to its card. Tactile mode only. Independent of stencil_thickness. (mm)
hinge_thickness = 0.6; // [0.3:0.1:1.2]

/* [Card IDs] */
// Raised ID text height on every card. Visual mode only - Tactile mode uses the fixed ADA character size. (mm)
id_text_size = 5; // [3:0.5:8]
// How far the ID letters stand proud of the top face, so they read by touch. Visual mode only. (mm)
id_emboss_height = 0.8; // [0.5:0.1:1]
// ID embossed on the lamp plug card - max 2 characters
p1_id = "P1";
// ID embossed on the standard 3-prong plug card - max 2 characters
p2_id = "P2";
// ID embossed on the heavy-duty plug card - max 2 characters
p3_id = "P3";
// ID embossed on the wide 2-prong appliance plug card - max 2 characters
p4_id = "P4";
// ID embossed on the ruler card - max 2 characters
r1_id = "R1";
// ID embossed on the cord gauge card - max 2 characters
c1_id = "C1";
// ID embossed on the first finger-sizing card - max 2 characters
f1_id = "F1";
// ID embossed on the second finger-sizing card - max 2 characters
f2_id = "F2";

/* [Print Bed] */
// Usable width of your print bed. Cards are packed onto sheets no bigger than this. (mm)
bed_width = 200; // [80:5:400]
// Usable depth of your print bed. (mm)
bed_depth = 200; // [80:5:400]
// Which sheet to render. 0 = preview every sheet at once, separated by 15 mm; 1-9 = render only that sheet for export.
part_index = 0; // [0:1:9]

/* [Export] */
// Upload helper. "All cards" lays every card onto print sheets (the normal layout, honouring the Print Bed sizes and part_index above). Pick a single card by its ID to render just that one stencil on its own at the origin - the way each card is uploaded as its own standalone model. A single card ignores the Print Bed / part_index settings. The list follows the fixed card order (P1-P4 plug gauges, R1 ruler, C1 cord gauge, F1/F2 finger sizing), so it still selects the right card even if you rename an ID above.
export_card = "All cards"; // [All cards, P1, P2, P3, P4, R1, C1, F1, F2]

/* [Hidden] */
eps = 0.01;

IS_TACTILE = (label_mode == "Tactile");

// ── Preset plug dimensions ──────────────────────────────────────────────────
// [id, length, width wall, width cable, thickness wall, thickness cable, cord]
// Copied from the `_eff_*` preset ternaries in src/Plug_Puller_Parametric.scad
// (lamp, standard 3-prong, heavy-duty, wide 2-prong appliance — the Step 1
// dropdown order).
// tests/test_stencil_data.py asserts these numbers match the main SCAD and
// scripts/generate_stencil_sheet.py — keep all three in lock-step.
PLUG_PRESET_DIMS = [
    ["P1", 37.0, 25.0, 11.2, 18.6, 8.6, 3.6],
    ["P2", 46.2, 26.6, 13.4, 18.9, 15.0, 7.0],
    ["P3", 43.8, 25.8, 21.9, 27.0, 27.0, 8.2],
    ["P4", 38.0, 34.0, 34.0, 16.0, 16.0, 5.0],
];
PLUG_PRESET_NAMES = [
    "LAMP 2-PRONG NEMA 1-15",
    "STANDARD 3-PRONG NEMA 5-15",
    "HEAVY-DUTY CORD NEMA 5-15",
    "WIDE 2-PRONG NEMA 1-15",
];
// Fixed card list indices: the P cards first, then the ruler, the cord gauge
// and the two finger cards. Every index-bound spot below reads these.
N_PLUG = len(PLUG_PRESET_DIMS);
I_R1 = N_PLUG;
I_C1 = N_PLUG + 1;
I_F1 = N_PLUG + 2;
I_F2 = N_PLUG + 3;

// The 18 finger gauge holes, grouped into rows exactly like the paper
// stencil sheet (docs/guides/stencil-sheet.svg).
F1_ROWS = [[15, 16, 17, 18, 19, 20], [21, 22, 23, 24, 25]];
F2_ROWS = [[26, 27, 28, 29], [30, 31, 32]];
FINGER_RULE_TEXT = "FINGER WIDTH = HOLE No. - 5";

// Cord gauge slot diameters (worksheet measurement 6).
CORD_GAUGE_DIAS = [3, 4, 5, 6, 7, 8, 9];

FONT_BOLD = "Liberation Sans:style=Bold";
FONT      = "Liberation Sans";

_deboss = min(deboss_depth, stencil_thickness - 0.4);

// ── Tactile lettering (ADA 703.2, values from the assistive-forge sign) ─────
ADA_CHAR_HEIGHT = 16;   // ADA 703.2.5: 15.9-50.8 mm
ADA_RAISE       = 0.8;  // ADA 703.2.1: >= 0.8 mm proud

// ── Grade 2 braille flap titles (ADA 703.3, Tactile mode) ───────────────────
// Grade 2 UEB, generated by scripts/generate_braille_labels.mjs — do not
// hand-edit; edit the wording there, re-run it, and paste the output.
// tests/test_braille_labels.py locks this constant to scripts/braille_labels.json.
// P1: "lamp", "2 prong"
// P2: "standard", "3 prong"
// P3: "heavy duty", "cord"
// P4: "wide plug", "2 prong"
// R1: "ruler 100 mm", "notches 10 mm"
// C1: "cord gauge mm"
// F1: "finger sizing 1 of 2", "width: hole minus 5"
// F2: "finger sizing 2 of 2", "width: hole minus 5"
BRAILLE_LABELS = [
    ["⠇⠁⠍⠏", "⠼⠃⠀⠏⠗⠰⠛"],
    ["⠌⠯⠜⠙", "⠼⠉⠀⠏⠗⠰⠛"],
    ["⠓⠂⠧⠽⠀⠙⠥⠞⠽", "⠉⠕⠗⠙"],
    ["⠺⠊⠙⠑⠀⠏⠇⠥⠛", "⠼⠃⠀⠏⠗⠰⠛"],
    ["⠗⠥⠇⠻⠀⠼⠁⠚⠚⠀⠍⠍", "⠝⠕⠞⠡⠑⠎⠀⠼⠁⠚⠀⠍⠍"],
    ["⠉⠕⠗⠙⠀⠛⠁⠥⠛⠑⠀⠍⠍"],
    ["⠋⠬⠻⠀⠎⠊⠵⠬⠀⠼⠁⠀⠷⠀⠼⠃", "⠺⠊⠙⠹⠒⠀⠓⠕⠇⠑⠀⠍⠔⠥⠎⠀⠼⠑"],
    ["⠋⠬⠻⠀⠎⠊⠵⠬⠀⠼⠃⠀⠷⠀⠼⠃", "⠺⠊⠙⠹⠒⠀⠓⠕⠇⠑⠀⠍⠔⠥⠎⠀⠼⠑"],
];
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

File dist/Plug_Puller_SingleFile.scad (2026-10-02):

// =============================================================================
// Plug_Puller_SingleFile.scad — GENERATED FILE, DO NOT EDIT
// =============================================================================
//
// Plug Puller — one-sided puller: the flattened single-file build of
// src/Plug_Puller_Parametric.scad, with fit_sizes.scad, fit_measured.scad and
// presets.scad inlined. Generated from the canonical sources in src/ — edit
// those files, not this one.
//
// Purpose: web customizers (MakerWorld Parametric Model Maker,
// openscad-playground `?src=` loading) accept only a single .scad file with
// no local include tree. This artifact renders identically to the modular
// build.
//
// Source repository:
//   https://github.com/BrennenJohnston/openscad-plug-puller
//
// License: PolyForm Noncommercial 1.0.0
//   https://polyformproject.org/licenses/noncommercial/1.0.0/
//   Personal, hobby, educational, research, and other noncommercial use is
//   permitted. Contact the maintainer for commercial use.
// =============================================================================

// Plug Puller 0.14.0 — Parametric Generator for the one-sided puller
// The one-sided puller is the reworked v6 flat puller: a slab with a
// two-level plug pocket whose side walls follow a parametric "plug side
// rail", plus rail-placed zip-tie holes and velcro slots, finger bores, and a
// chiral J-hook cord catch. Its Medium defaults descend from the v6 Plug
// Puller ("Plug Puller 3.1 - B") but are no longer a sub-mm mesh clone.
// The two-sided puller (two plates that zip-tie around a plug) is its own file: src/Plug_Puller_Two_Sided.scad.
//
// ── Quick Start (the numbered Steps are all a beginner needs) ───────────────
//   1. Open this file in OpenSCAD (v2021.01 or later recommended)
//   2. Show the Customizer panel: View ▸ Hide Customizer — make sure it is
//      UNCHECKED (older builds: Window ▸ Customizer)
//   3. Fill in the numbered Steps top to bottom:
//        Step 1: Your plug — pick a plug preset, or measure your plug
//                (docs/guides/one-sided/quick-start.md shows every
//                measurement).
//        Step 2: Size — Medium is the reference; Small / Large for other
//                hands; "Measure my hand" to type two hand numbers.
//        Step 3: Attachment — how the tool straps onto the plug.
//        Step 4: Cord hook — right- or left-handed cord catch.
//   4. Press F6 to render, then File ▸ Export ▸ STL to save your print file
//
//   The Customizer is organized in three tiers:
//     "Step 1" … "Step 4"       the guided path — beginners stop here
//     "Advanced - …" sections   power dials: manual zip/velcro placement and
//                               render quality
//                               (see docs/guides/one-sided/full-guide.md)
//     "… (Custom size only)"    expert geometry sliders, active only when
//                               Size = Custom (all measurements are ignored)
// ─────────────────────────────────────────────────────────────────────────────
//
// Coordinate frame:
//   X = 0 at horizontal midline (symmetric)
//   Y = 0 at cord/T-hook end (narrow end), positive toward plug end
//   Z = 0 at print bed, positive upward
//
// Plug side rail (the "few dials, max agency" concept):
//   A 2D line describing the plug's side edge inside the tool, defined by the
//   pocket half-width at the plug face and one `pocket_side_angle` taper.
//   Zip stations and velcro slots are positioned as (t, d) = (mm along the
//   rail from the plug face,
//   mm outward-normal offset) so one slider slides a feature coherently along
//   the plug's side. See rail_point()/rail_feature_center() below.
//
// Architecture:
//   1. Body slab: octagonal control polygon; when `body_round_bottom_only`
//      is set, the cord half is opened (offset-rounded) into the organic
//      blob of the original while the plug end stays crisp
//   2. Plug pocket: a taper-aware recess (side walls follow the plug rail,
//      rounded nose) plus a deeper circular seat disc centered on the top
//      edge (partial-depth cuts; no fill pieces needed)
//   3. Subtract feature cutouts (holes, notches, slots)

// ═══════════════════════════════════════════════════════════════════════════════
// CUSTOMIZER PARAMETERS
// ═══════════════════════════════════════════════════════════════════════════════
// UI tiers (file order = Customizer order):
//   Steps 1-4                    the guided beginner path
//   "Advanced - …"               power dials for experienced users
//   [Hidden]                     programmatic switches, not shown in the UI
//   "… (Custom size only)"       expert sliders, active only in Size = Custom

// MAINTAINER NOTE: dropdown option labels must not contain parentheses — the
// OpenSCAD Customizer fails to parse such enum values and silently reverts
// the selection to the default (MakerWorld PMM inherits this behaviour).
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

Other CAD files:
tests/fixtures/medium_with_velcro/reference.stl
stl/Measuring-Stencil/Visual/Measuring-Stencil_Visual_P2_Standard-3-Prong-Gauge.stl
stl/Plug-Puller/Plug-Puller_Two-Sided_Flat-2-Prong-Lamp-NEMA-1-15_Medium.stl
stl/Measuring-Stencil/Tactile/Measuring-Stencil_Tactile_P1_Lamp-Plug-Gauge.stl
dist/Plug_Puller_Two_Sided_SingleFile.scad
src/Plug_Puller_Two_Sided.scad
src/fit_measured.scad
src/fit_sizes.scad
src/presets.scad
stl/Measuring-Stencil/Tactile/Measuring-Stencil_Tactile_C1_Cord-Gauge.stl
stl/Measuring-Stencil/Tactile/Measuring-Stencil_Tactile_F2_Finger-Sizing-26-32mm.stl
stl/Measuring-Stencil/Tactile/Measuring-Stencil_Tactile_P3_Heavy-Duty-Cord-Gauge.stl
stl/Measuring-Stencil/Tactile/Measuring-Stencil_Tactile_P4_Wide-2-Prong-Appliance-Gauge.stl
stl/Measuring-Stencil/Visual/Measuring-Stencil_Visual_All-Cards.stl
stl/Measuring-Stencil/Visual/Measuring-Stencil_Visual_C1_Cord-Gauge.stl
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

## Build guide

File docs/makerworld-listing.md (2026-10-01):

# MakerWorld Listing — Plug Puller

Status: **cleared to publish.** The licensing decision below is made. The
text in this document is finished and ready to paste; upload once the
pre-publish checklist at the end is done.

Upload files: [`dist/Plug_Puller_SingleFile.scad`](../dist/Plug_Puller_SingleFile.scad)
(the one-sided puller) and
[`dist/Plug_Puller_Two_Sided_SingleFile.scad`](../dist/Plug_Puller_Two_Sided_SingleFile.scad)
(the two-sided puller).

Written to the shared
[Accessible MakerWorld Documentation Standard](https://github.com/BrennenJohnston/accessible-makerworld-doc-standard/blob/main/ACCESSIBLE_MAKERWORLD_DOC_STANDARD.md).

---

## Licensing decision — made 2026-09-30

This repository is licensed **PolyForm Noncommercial 1.0.0**. Publishing to
MakerWorld requires accepting MakerWorld's terms of service, which grant the
platform a license to host, display, and distribute the uploaded model, and
require choosing one of MakerWorld's listing licenses (a Creative Commons variant
or Bambu Lab's Standard Digital File License) for downloaders. That platform grant
sits **alongside** — and for MakerWorld downloads, effectively in front of —
PolyForm NC.

**The maintainer chose Option A on 2026-09-30:** publish on MakerWorld, with
**CC BY-NC-SA 4.0** as the listing license. Downloads via MakerWorld follow
that license; the GitHub repository stays PolyForm NC 1.0.0.

The two options that were weighed:

- **Option A — publish on MakerWorld:** accept the platform grant and pick the
  listing license closest to PolyForm NC's intent (recommended: **CC BY-NC-SA
  4.0** — noncommercial, attribution, share-alike). Downloads via MakerWorld
  follow that CC license; the GitHub repo stays PolyForm NC.
- **Option B — stay Forge-only:** skip MakerWorld; the zero-install path
  remains the Assistive Forge link in the README, which opens a copy of the
  file from the Forge's example branch under PolyForm NC with no platform
  grant.

---

## Upload fields

| Field | Value |
|---|---|
| Model title | `Plug Puller - Parametric Assistive Plug Remover (fits YOUR plug and YOUR hand)` |
| Designer | Brennen Johnston |
| Category | Health & Personal Care → Assistive Devices (or Tools → Hand Tools if unavailable) |
| License | **CC BY-NC-SA 4.0**, the maintainer's choice; see the licensing decision above. |
| Upload files | `dist/Plug_Puller_SingleFile.scad` (the one-sided puller) and `dist/Plug_Puller_Two_Sided_SingleFile.scad` (the two-sided puller), each as its own customizable file. Both are generated; see the pre-publish checklist. |
| Tags | `assistive technology`, `accessibility`, `arthritis`, `grip aid`, `plug puller`, `outlet`, `parametric`, `openscad`, `customizer`, `adaptive equipment`, `occupational therapy` |
| External link | <https://github.com/BrennenJohnston/openscad-plug-puller> (source repository) |

## Summary

A handheld assistive tool that helps people with limited grip strength,
arthritis, or small hands remove electrical plugs from wall outlets safely — by
pulling the plug, never the cord. Fully parametric: type a few ruler measurements
into the customizer and get a tool shaped to your exact plug, outlet plate, and
hand. Two tools, two customizable files: a one-sided puller for typical plugs and
a two-sided puller — two plates that zip-tie around the plug — for fat
extension-cord plugs, USB-C tips, and charger plugs.

## Description

*Paste into MakerWorld's description body.*

**What it is**

The Plug Puller grips a plugged-in plug and gives you two large finger holes, so
removing the plug uses your whole hand instead of a fingertip pinch. It touches
only the plug's sides and back — never between the plug face and the wall.

Two tools, each in its own customizable file:

The **one-sided puller** is a single slab with a pocket shaped to your plug, two
finger holes, a J-hook for the cord, and slots for zip ties or a velcro strap.
Slide it over the plug and pull with your whole hand. Print one.

The **two-sided puller** is for fat round extension-cord plugs, USB-C tips, and
charger plugs. Two identical serrated plates grip the plug's sides and zip ties
cinch them together. The download holds **both plates**: print it, flip one
plate over, and zip-tie the pair face to face. If your plug is 24 millimeters or
more thick, the one-sided file shows a red tag sending you here.

**Customize it to your plug and hand — this is the whole point**

Open the **Customize** panel on the file for your tool and work top to bottom.
The sections are numbered and every measurement is in millimeters.

In the one-sided puller:

*Step 1 — Your plug.* Either pick a preset in `plug_preset` — flat 2-prong lamp
plug (NEMA 1-15), standard 3-prong (NEMA 5-15) or wide 2-prong appliance plug
(NEMA 1-15) — or set it to `Measure my plug` and type six numbers: plug length,
width at the prong end, width at the cord end, thickness at the prong end,
thickness at the cord end, and cord thickness. Then choose your wall-plate style in
`measure_wall_plate_style` (standard flat plate, Decora rocker, oversized jumbo,
or no plate) so the tool straddles the plate and sits flat against the wall.

*Step 2 — Size.* `size` offers Small, Medium (default), and Large grips, built
from ANSUR II 2012 hand anthropometry spanning roughly the 5th percentile female
to the 95th percentile male. Or set it to `Measure my hand` and type your finger
knuckle width and hand width.

*Step 3 — Attachment.* `attachment` gives you zip-tie holes, velcro strap slots,
both (the default), or none.

*Step 4 — Cord hook.* `hook_hand` is `Right` or `Left`.

In the two-sided puller:

*Step 1 — Your plug.* Either pick a preset in `plug_preset` — heavy-duty
extension cord (NEMA 5-15), USB-C laptop tip, flat 2-prong lamp plug
(NEMA 1-15) or standard 3-prong (NEMA 5-15) — or set it to `Measure my plug`
and type four numbers: plug length, the plug's width at the prong end and at
the cord end (the size the two plates close across), and cord thickness. If
you measured, then pick `plug_sides`: `Rounded sides` for a round plug, a USB-C
or charger tip (the plates get a sloped cradle that centers it), or
`Flat sides` for a boxy plug.

*Step 2 — Size.* Small, Medium (default), Large, or `Measure my hand` with your
finger knuckle width.

*Step 3 — Attachment.* Zip ties plus a velcro strap slot in each arm (the
default), or zip ties only. The zip ties hold the two plates together. On a
short plug, such as a USB-C tip, there is no room for the strap slot and it
is left out; the zip ties still hold the plates.

*Step 4 — Print layout.* Keep `Both plates`: one download prints the whole tool.

Everything below Step 4 is optional power-user tuning.

**Bad numbers cannot fail silently.** If a measurement is out of range or the
geometry cannot work, the model renders a **red warning tag** naming the
measurement to fix — as actual 3D text in the rendered model, not a console
message. Fix the warning before you export: the red tag is part of the exported
model and would otherwise print as an extra object on your bed. (In the desktop
app's preview, a green tag also confirms which numbers were applied; MakerWorld
renders the finished model only, so it does not show there.)

**Print settings**

- Orientation: flat face down, pocket up; the two-sided puller's plates flat, as
  they lie in the file. No supports.
- Layer height: 0.2 millimeters, or 0.16 for crisper rim fillets.
- Walls: 3 to 4. Infill: 25 to 35 percent, cubic or gyroid.
- Material: **PETG recommended** — it handles repeated flexing and the warmth near
  an outlet better than PLA. PLA, ABS, and ASA all work. **Do not use flexible
  filament**; the tool has to stay rigid to transmit force to the plug.
- Two-sided puller: the file holds **both plates**; flip one after printing and
  zip-tie the pair face to face around the plug.
- The `quality` slider defaults to 64 circle segments, which is print-ready. Drop
  it to 32 for fast test renders and put it back before you export.

**Safety**

The tool grips only the plug body's sides and back face. Nothing is inserted
between the plug and the outlet and no conductive parts are involved. Inspect
prints for cracks before each use and reprint if damaged. For round plugs with
little for the pocket to grip, a zip tie through the attachment holes adds
security.

**Try it before you print**

The source repository has printable 1:1 outline sheets so you can hold a paper
version of the tool against your plug before committing filament, and a printable
**measuring stencil** — a set of thin cards with plug silhouette gauges, a 100
millimeter tactile ruler, a cord-thickness gauge, and eighteen finger-sizing holes.
The stencil lets you find your numbers by matching shapes instead of reading a
ruler, which matters if reading a ruler is the hard part.

The stencil comes in a **tactile version** with raised ADA-size characters and a
**braille title flap on every card**. The braille is generated at build time with
liblouis in UEB Grade 2 and baked into the model, so there is no translation step
for you — the labels are simply there. Note that the measuring stencil is a
separate file in the repository, not part of this MakerWorld model.

**More resources**

The source repository has each tool's quick start and full guide, as pages and
as printable PDFs: how to measure, every dial, and fit troubleshooting. It also
has the outline sheets, the measuring stencil and the engineering reference:
<https://github.com/BrennenJohnston/openscad-plug-puller>

**Credits**

- Design and code: Brennen Johnston.
- Hand sizing from ANSUR II (2012) and Rogers (2008) anthropometry.
- Tactile stencil labels follow the 2010 ADA Standards §703.2 raised-character
  and §703.3 braille figures; braille translation by the open-source liblouis
  library.

## Print profile notes

There is no `.3mf` to attach — the geometry depends on the user's plug and hand
measurements, so no single sliced profile fits. The settings are stated as text in
the description, which is also the accessible choice: a screen-reader user cannot
read a slicer screenshot, and a 2025 study of Cura, PrusaSlicer, and Bambu Studio
found much of their interfaces invisible to the accessibility APIs screen readers
depend on.

| Setting | Value |
|---|---|
| Orientation | flat face down, pocket up |
| Layer height | 0.2 mm (0.16 mm for crisper rim fillets) |
| Walls | 3–4 |
| Infill | 25–35% cubic or gyroid |
| Material | PETG recommended; PLA / ABS / ASA fine; no flexibles |
| Supports | none |
| `quality` | 64 for export, 32 for test renders |

If a print profile is added later, the sensible candidate is the default Medium
one-sided puller with the standard 3-prong preset, and it needs its own photograph
of the actual printed result.

## Gallery plan

1. **Cover — the tool in use on a real outlet.** A hand with fingers through both
   finger holes, tool seated on a plugged-in plug.
   **Alt text:** A printed plug puller seated over a plug in a wall outlet, with a
   hand's fingers through its two large finger holes, ready to pull.

2. **The one-sided puller alone, pocket up.** Three-quarter view showing the plug pocket,
   finger holes, J-hook, and attachment slots.
   **Alt text:** A flat printed tool about 80 millimeters long with a shaped
   pocket at one end, two round finger holes, a J-shaped hook, and slots for zip
   ties.

3. **The tool straddling a wall plate.** Side view against the outlet, showing it
   sits flat and touches only the plug's sides and back.
   **Alt text:** Side view of the tool against a wall outlet, straddling the
   cover plate and gripping only the sides and back of the plug — nothing between
   the plug and the outlet.

4. **The two-sided puller on an extension cord.** Two plates zip-tied face to
   face around a fat round plug (`docs/images/two-sided-assembled-on-plug.jpg`).
   **Alt text:** The blue two-sided puller zip-tied around an orange extension-cord plug, black zip ties through its arms, the brass prongs past the arm tips.

5. **The two plates apart.** Both plates side by side, as they come off the
   printer, with the plug between them, showing the serrated grip zone, the
   strap slots and the zip-tie stations (`docs/images/two-sided-plates-and-plug.jpg`).
   **Alt text:** Two identical blue plates with an orange extension-cord plug between them; each has two finger holes, toothed arms, strap slots and zip-tie holes.

6. **The three hand sizes, printed.** Small, Medium, and Large one-sided pullers
   on three plugs (`docs/images/one-sided-three-sizes.jpg`).
   **Alt text:** Three one-sided pullers side by side on the printer bed, Large on an orange extension-cord plug, Medium on a black three-prong plug, Small on a black lamp plug.

7. **A red warning tag in the preview.** The preview with the red 3D warning text
   on a deliberately bad measurement (`docs/images/one-sided-warning-tag-preview.png`,
   rendered by `scripts/render_doc_images.py` with a 27 mm thick plug).
   **Alt text:** The one-sided puller in the preview with red text lying beside it reading WARNING: PLUG THICKER THAN 24MM - USE THE TWO-SIDED PULLER FILE, which is how the tool reports a plug it cannot hold.

8. **The measuring stencil, tactile version.** Printed cards with raised
   characters and the braille flaps.
   **Alt text:** Thin printed measuring cards with plug-shaped cutouts, a
   notched ruler, and raised braille labels on a folded flap along each card's
   edge.

The cover must be a photograph of the actual printed object, not a render.
MakerWorld requires at least one real print photo per model and per print
profile.

## Pre-publish checklist

- [x] **Maintainer has signed off on the licensing decision above.** Done
      2026-09-30: Option A, CC BY-NC-SA 4.0.
- [x] **Repo is public** — the listing links back to GitHub.
- [ ] **Both single files are fresh** — `dist/Plug_Puller_SingleFile.scad` and
      `dist/Plug_Puller_Two_Sided_SingleFile.scad`. They are generated, not
      hand-edited. Run `python scripts/build_flattened.py --check` (it checks
      both); if it fails, run `python scripts/build_flattened.py` and commit the
      result. Uploading a stale flattened file ships different geometry than
      `src/`.
- [ ] **Both files uploaded,** each as its own customizable file on the one
      design page.
- [ ] **Single-file requirement verified.** The build script asserts the output
      contains no remaining `include`/`use` statements, and
      `tests/test_flattened_build.py` verifies render parity against the golden
      fixtures.
- [ ] **Customizer dropdown hygiene verified.** Run `pytest -m
      "not requires_openscad"` —
      `tests/test_openscad_customizer.py::test_no_parentheses_in_dropdown_options`
      is the important one, because a parenthesis in an option label makes the
      customizer silently revert the user's selection. The same module checks for
      `value:Label` syntax, defaults missing from their own option list, and that
      `render_mode` stays in the Hidden section.
- [ ] **Creator Portal smoke test.** Upload each file via Creator Portal → Open
      SCAD File and click through Steps 1–4 in MakerWorld's parameter form.
- [ ] **Cloud render verified for both tools.** Render the default Medium
      one-sided puller, then the two-sided file at its defaults and with the
      heavy-duty extension cord preset, and confirm each finishes inside the
      hosted renderer's timeout.
- [ ] **Pair download verified.** The two-sided file's download holds both
      plates side by side (two separate parts in one STL).
- [x] **Plug preset label confirmed.** The maintainer decided that
      `Heavy-duty extension cord - NEMA 5-15` keeps its name (it names the plug,
      not the tool).
- [ ] **Warning tags confirmed visible on MakerWorld.** Set
      `measure_plug_width_prong_end` to an out-of-range value and confirm the red 3D
      warning text renders in the hosted preview. This model's warnings are real
      geometry rather than console output, which is exactly why it works on a
      platform with no console — verify it, because it is the model's main
      accessibility feature.
- [ ] **Every gallery image has alt text pasted into MakerWorld's field.**
- [ ] **Cover photo is a real printed object,** in use on an actual outlet.
- [ ] **Quick start linked from the description** — either the GitHub link to
      [`MAKERWORLD_QUICK_START.md`](MAKERWORLD_QUICK_START.md) or its content
      pasted into the instructions area.

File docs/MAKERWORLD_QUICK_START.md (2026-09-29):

# MakerWorld Quick Start — Plug Puller

This page goes with the MakerWorld listing. It covers what is particular to
MakerWorld: which file to upload, how its customizer differs from the
desktop program, and where the full instructions are.

The Plug Puller comes as two tools, each a single file that is the whole
upload for its tool:

- the **one-sided puller**,
  [`dist/Plug_Puller_SingleFile.scad`](../dist/Plug_Puller_SingleFile.scad):
  one slab with a pocket shaped to your plug, two finger holes and a cord
  hook, for lamp plugs, standard 3-prong plugs and other plugs thinner than
  24 mm. Print one.
- the **two-sided puller**,
  [`dist/Plug_Puller_Two_Sided_SingleFile.scad`](../dist/Plug_Puller_Two_Sided_SingleFile.scad):
  two identical serrated plates that zip-tie around a thick round
  extension-cord plug, a USB-C tip or a charger plug. The download holds
  both plates: print it, flip one plate over, and zip-tie the pair face to
  face.

If your plug is 24 mm thick or more, the one-sided file shows a red tag,
`PLUG THICKER THAN 24MM - USE THE TWO-SIDED PULLER FILE`: switch to the
two-sided file.

Each tool has a **quick start** (get the file, measure, the four Customizer
steps, print, assemble, use) and a **full guide** (every dial with a
picture, fit troubleshooting, every warning, the advanced dials), each as a
page and as a printable PDF whose last pages are the measuring form and the
paper measuring stencil at true size:

| Tool | Quick start | Full guide |
| ---- | --- | --- |
| One-sided puller | [page](guides/one-sided/quick-start.md), [PDF](Plug_Puller_One_Sided_Quick_Start.pdf) | [page](guides/one-sided/full-guide.md), [PDF](Plug_Puller_One_Sided_Full_Guide.pdf) |
| Two-sided puller | [page](guides/two-sided/quick-start.md), [PDF](Plug_Puller_Two_Sided_Quick_Start.pdf) | [page](guides/two-sided/full-guide.md), [PDF](Plug_Puller_Two_Sided_Full_Guide.pdf) |

---

## Using the MakerWorld customizer

1. Go to MakerWorld, then **Create**, then **Parametric Model Maker**, and
   upload the file for your tool.
2. Work the form top to bottom: **Step 1 - Your Plug** (a preset, or
   `Measure my plug` and your numbers in mm), **Step 2 - Size**, **Step 3 -
   Attachment**, then Step 4. The quick start explains every field; the
   full guide shows a picture of what each one changes. Everything below
   Step 4 is optional.
3. Generate and render, then look at the rendered model for **red text**
   beside the part. It names a measurement to fix, and it is part of the
   model: exported with it, it prints as an extra object on your bed. Clear
   every red tag before you download.
4. Download the STL and print it with the settings in the quick start:
   flat on the bed as modeled, no supports, 0.2 mm layers, 3 to 4 walls, 25
   to 35 percent infill, PETG.

## What MakerWorld's preview does not show

MakerWorld renders the finished model only. The red warning tags show,
because they are part of the model. These do not:

- the see-through plug that the desktop program draws from your numbers;
- the green tag that confirms which numbers were applied (one-sided);
- the orange notes about ignored Custom dials, auto-fit adjustments
  (one-sided) and a strap slot left out for a short plug (two-sided).

If you want to see them, open the same file in the desktop program or in
the browser, as the quick start's "Get the file" section describes.

## Other ways to customize

- **The OpenSCAD Assistive Forge**, our browser version of OpenSCAD built
  for keyboard and screen reader use, with no account and no upload. One
  link opens the tool ready to customize, shows the four steps' dials
  first, and offers to keep a copy in your browser:
  [the one-sided puller](https://openscad-assistive-forge.pages.dev/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)
  or
  [the two-sided puller](https://openscad-assistive-forge.pages.dev/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).
  Like MakerWorld it shows the red warnings but not the see-through plug.
  The full guide's "Working in the browser" section has the details.
- **Desktop OpenSCAD**: the design is a text file, the Customizer panel is
  native, and the console messages are readable, including the auto-fit
  detail that neither MakerWorld nor the browser shows.

## Resources

- [This project on GitHub](https://github.com/BrennenJohnston/openscad-plug-puller)
- [Smith-Kettlewell *3D Printing for Blind & Low Vision Makers*](https://www.ski.org/technical-file/3d-printing-for-bvi-makers/):
  printer and slicer guidance for the part of the workflow this model
  cannot cover. Slicer accessibility is a real barrier:
  [Ballarin, Stangl, Oswal, Whiting, DIS 2025](https://doi.org/10.1145/3715668.3736342)
  measured that much of Cura's, PrusaSlicer's and Bambu Studio's interfaces
  is invisible to the accessibility APIs screen readers use, which is why
  the print settings in the guides are written out as text rather than
  shown as a screenshot.

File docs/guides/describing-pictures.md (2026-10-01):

# Describing pictures

Every picture in this project's guides has two text parts: a short alt text that says what the picture is, and a long description that carries what the picture shows. The dial pictures under `docs/dials/`, the storyboards and the measuring form sheets get theirs from `scripts/generate_dial_diagrams.py` and `scripts/generate_measuring_form.py`, written by rules, so all of them have the same shape; the owner reads a sample before they ship. This page gives the ten rules with their sources, the three templates the generator fills in, three examples as generated, and what to do when you write one by hand for a photo.

## The ten rules

1. **Two parts for every complex picture.** A short alt text that identifies the picture and says where the long description is, and a long description in the page text with the information the picture carries. Source: the W3C Web Accessibility Initiative, [Complex images](https://www.w3.org/WAI/tutorials/images/complex/); NCAM's guideline 4 (a brief summary followed by extended description), read 2026-09-26.
2. **No "image of".** The alt text never opens with "image of", "picture of", "photo of" or "diagram of"; a screen reader already says it is an image. It names the kind of picture only when the kind matters, as in "before and after". Source: [WebAIM, Alternative Text](https://webaim.org/techniques/alttext/), read 2026-09-26; the Accessible MakerWorld Documentation Standard, section 1.4; the docs gate (`scripts/check_docs.py`) enforces it.
3. **Overview first, then details.** One sentence on what the picture is, then the panels left to right, then the marked parts as a numbered list whose numbers are the ones drawn on the picture. Source: [NCAM, Guidelines for Describing STEM Images](https://www.wgbh.org/foundation/services/ncam/tools-resources/effective-practices-for-description-of-science-content-guidelines-for-describing-stem-images), guideline 4, read 2026-09-26; Zong and others, [Rich Screen Reader Experiences for Accessible Data Visualization](https://arxiv.org/abs/2205.04917), 2022, on structure and navigation; the Perkins School for the Blind, [Creating image descriptions](https://www.perkins.org/resource/creating-image-descriptions-alt-text/), "general to specific", read 2026-09-27.
4. **Say the data, not the appearance.** The values with their units, the direction of the change, and the part names the guides use; a color is named in the key and never carries the meaning alone. Source: NCAM, guidelines 2 and 5; WebAIM (accurate and equivalent); Perkins, "be objective".
5. **One spatial vocabulary everywhere.** The plug end is the top of the picture and the cord end the bottom; left and right as printed; the part names are the ones the catalog's "Moves" lines and the picture's key use. Source: Perkins, "consider your audience" and "tone and language" (the reader's own vocabulary); the DIAGRAM Center's image description guidelines say the same by report (see the note under the sources).
6. **Short.** An alt text of at most 150 characters; a dial's long description of at most 90 words, or 110 when its picture has a red dimension line, which the description also explains; a storyboard's of at most 150; no sentence repeats the card's own text. Source: WebAIM (succinct, not redundant); NCAM, guideline 1 (brevity); Perkins, "be concise".
7. **A process is a numbered list.** One line per stage, never a paragraph, each line named as the picture names it: a storyboard's lines read Start, then Step 1 to Step 4, the numbers on its arrows. Source: NCAM, guideline 6.
8. **Say what did not change** when the change is small or none. Source: Zong and others, 2022 (readers compare); the project's accessibility rule that a text reader must never have to guess.
9. **Where the text lives.** The SVG's `desc` element carries the long description; the Markdown page puts it as visible text right under the image; the PDF wraps the picture in a `figure` with the long description as its caption; no `longdesc` attribute. Source: the W3C tutorial's figure approach; WebAIM (`longdesc` is deprecated).
10. **Every description is a reviewed string.** Each alt text and long description is proposed text until the project owner has read a sample of it. Source: the project's rule that accessibility-critical text is read by a person before it is final.

---

## The sources, and the two not opened

The W3C tutorial pages, WebAIM, NCAM and the arXiv abstract were read on 2026-09-26; the Perkins page on 2026-09-27 in a browser (it names the DIAGRAM Center and WebAIM as its own sources and adds "context is key", "consider your audience", "be concise", "be objective", "general to specific", "tone and language"; nothing in it contradicts the rules above). The DIAGRAM Center's [Image Description Guidelines](http://diagramcenter.org/table-of-contents-2.html) could not be opened on either day: the fetch tool rejected the site's certificate on 2026-09-26 and a browser showed an error page for both its http and https addresses on 2026-09-27. What this page says about them is by report only (a search result and the Perkins page): a two-part text alternative, and processes as nested lists, which rules 1 and 7 already say.

---

## The alt text template

```text
{title}: before and after, {before} to {after} {unit}; red marks {the parts, each with "the", joined with commas and "and"}.
```

When that runs past 150 characters, the parts are counted instead: `…; red marks 6 parts, named below.` A dial that changes no shape gets `{title}: changes no shape.` The two-sided print layout, drawn as one panel, gets `{title}: one view, {before} to {after}; the layout with both plates, nothing marked.`

---

## The long description template

```text
Two top views of {the one-sided puller | one plate of the two-sided puller}, before left and after right, the plug end at the top.
Left: the defaults{ with {dial} set to {value}}, a {w} mm wide plug in teal.
Right: {title} {at {value} {unit} | set to {value}}: {the changes sentence}.
The red line marks {the part} and reads {value} {unit}, the number you type{; {the part} is drawn {size} mm {wide | long | across}, {why}}.
Marked in red: 1, {the part}: {where it sits}. 2, {the parts}: {where they sit}{, removed}. …
{The unnamed parts, up to four} stay where they were. | Everything else follows the outline.
```

A section row opens with `Two vertical slices of {the tool} at {x | y} = {at} mm, before left and after right, the top face up.` and its left panel says `the plug in teal in the cut`. When the whole runs past 90 words, or 110 with a red dimension line, the generator drops the closing sentence first, then the changes sentence, then the locations of the entries that carry several names, then every location; the numbered list and the red-line sentence are never dropped.

The red-line sentence comes only on the measuring pictures that draw a dimension line. It gives the drawn size only when that size differs from the number by half a millimeter or more, one slider step, with the reason from one table per anchor in the generator (`DIMENSION_WORDS`): a hook slot or cord channel drawn wider than the cord so the cord slips in, a finger hole drawn wider than the finger, and a body narrower than the hand because its width is worked out from the hand width. Where a part sits comes from one table per tool in the generator (`FEATURE_LOCATIONS`): for the one-sided puller the body edge is "the outer outline", the pocket "the plug recess on the centerline", the seat "the round recess at the plug end", the wall notch "the notch in the top edge", the wing openings "the two openings beside the pocket", the zip-tie holes "the four small holes beside the pocket", the finger holes "the two large holes in the lower half", the hook "the cord hook slot in the bottom edge"; for the two-sided puller the plate edge is "the outer outline", the arms "the two toothed arms in the upper half", the teeth "the serrated inner edges of the arms", the finger lobes "the two rounded lobes in the lower half", the cord channel "the gap between the lobes at the bottom", the zip stations "the three small holes along each arm", the strap slot "the long slot in each arm".

---

## The storyboard template

```text
Five stages of {the tool}, left to right, the top row first, the plug end at the top; arrows numbered 1 to 4 show the steps, and red dashes mark the edges each step moved.
Start, the defaults: the tool as the file opens, with a {w} mm wide plug in teal.
Step 1 - {name}: {each dial with its value | each dial's name}; red on {the parts}{; {the parts} removed, drawn in red from the old outline}.
…
Step 4 - {name}: {the same}.
```

Every dial a step sets is named: with its value when the whole fits in 150 words, by its name alone when it does not. When the names alone still run long, each list of parts takes a single "the": "red on the body edge, finger holes and seat". A pair of dials taken at the prong end and at the cord end is named once, as "plug width at both ends", with one value when the two match. A step that moves nothing says so, and the two-sided print layout step says it puts both plates side by side in one file.

---

## Three examples, as generated

**Plug width at the prong end** (one-sided, 25 to 32 mm).

Alt text: Plug width at the prong end: before and after, 25 to 32 mm; red marks 5 parts, named below.

Long description: Two top views of the one-sided puller, before left and after right, the plug end at the top. Left: the defaults, a 25 mm wide plug in teal. Right: plug width at the prong end at 32 mm. The red line marks the plug's width at the prong end and reads 32 mm, the number you type. Marked in red: 1, the zip-tie holes: the four small holes beside the pocket. 2, the wing openings: the two openings beside the pocket. 3, the wall notch, the seat and the body edge: the notch in the top edge; the round recess at the plug end; the outer outline.

**Pocket depth** (one-sided, Custom size, 24.5 to 34 mm).

Alt text: Pocket depth: before and after, 24.5 to 34 mm; red marks the pocket and the wing openings.

Long description: Two top views of the one-sided puller, before left and after right, the plug end at the top. Left: the defaults with hand size set to Custom, a 25 mm wide plug in teal. Right: pocket depth at 34 mm: runs the plug recess farther from the plug end toward the finger holes. Marked in red: 1, the pocket: the plug recess on the centerline. 2, the wing openings: the two openings beside the pocket.

**Cord thickness** (two-sided, 4 to 9 mm).

Alt text: Cord thickness: before and after, 4 to 9 mm; red marks the arms, the cord channel, the finger lobes and the zip stations.

Long description: Two top views of one plate of the two-sided puller, before left and after right, the plug end at the top. Left: the defaults, a 20 mm wide plug in teal. Right: cord thickness at 9 mm. The red line marks the cord channel and reads 9 mm, the number you type; the channel is drawn 9.8 mm wide, so the cord slips in. Marked in red: 1, the finger lobes and the cord channel. 2, the finger lobes: the two rounded lobes in the lower half. 3, the finger lobes and the arms. 4, the zip stations: the three small holes along each arm.

Every generated text is in `docs/dials/dial_diagrams_index.json` (`alt` and `long_description`) and on the page [Dial diagrams](../dials/README.md), the alt on the image and the long description right under it.

---

## When you write one by hand

A photo in the guides follows the same rules, by hand: say what the photo shows and what the reader is meant to see in it, in the guides' own words for the parts; never open with "photo of"; keep it under 150 characters and put anything longer in the paragraph next to it; say the numbers with "mm"; and flag the text for the owner's reading before it ships, as the Accessible MakerWorld Documentation Standard, section 1.4, asks. The docs gate checks every image for an alt text and for the forbidden openers; it cannot check that the words are true, so someone reads them.

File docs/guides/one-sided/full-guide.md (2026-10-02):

# Full guide, one-sided puller

Everything about the one-sided puller: getting the file, measuring, every dial with a picture, printing, assembly, use and care, what to do when a print does not fit, every warning, and how the advanced dials work.

Model version 0.14.0. [The printable full guide](../../Plug_Puller_One_Sided_Full_Guide.pdf) has the same text, with the measuring form and the paper stencil sheets at true size as its last pages. The other document for this tool is [the quick start](quick-start.md). Each dial is headed by its plain name, with the name the Customizer shows on the line under it.

## Which tool this is

This guide is for the one-sided puller, src/Plug_Puller_Parametric.scad: the tool for a wall plug up to 24 mm thick, a pocket around the plug's back and sides with two finger holes below it, pulled with one hand. Measure your plug's thickness first. Thicker than 24 mm, or a plug you want held from both sides such as a USB-C tip or a round extension-cord plug, is the two-sided puller's job, and that tool has its own guide.

The Customizer's four steps are your plug, your size, the attachment and the hook's side. This full guide covers getting the file, measuring your plug and your hand or matching a card, every dial with a picture, printing, assembly, use and care, what to do when a print does not fit, every warning, and how the advanced dials work.

If red text appears beside the part in the preview, read it: it names the measurement to fix, and the part will not fit until it is gone.

In every picture: black = the tool; teal = your plug; red dashed = the edges this dial moved; the numbers match the key beside the picture.

The one-sided puller, the four Customizer steps on a US vacuum plug, five stages left to right.

Five stages of the one-sided puller, left to right, the top row first, the plug end at the top; arrows numbered 1 to 4 show the steps, and red dashes mark the edges each step moved. Start, the defaults: the tool as the file opens, with a 25 mm wide plug in teal. Step 1 - Your Plug: plug length, plug width at both ends, plug thickness at both ends, cord thickness, outlet cover plate style; red on the body edge, finger holes, seat, wall notch, wing openings and zip-tie holes. Step 2 - Size: hand size, finger width, hand width; red on the body edge, finger holes, pocket, wall notch, wing openings and zip-tie holes. Step 3 - Attachment: attachment; the wing openings removed, drawn in red from the old outline. Step 4 - Cord Hook: hook side; red on the hook.

- Step 1: type your plug's numbers
- Step 2: pick your hand size
- Step 3: pick how it attaches
- Step 4: pick the hook's side

## Get the file

The one-sided puller is the file `src/Plug_Puller_Parametric.scad`. There are two ways to open it and fill in its form: in your web browser with nothing to install, or in the free OpenSCAD program on your computer. Both show the same form, called the Customizer.

### In your browser

The OpenSCAD Assistive Forge is a version of OpenSCAD that runs in your browser, on a computer or a phone, built for keyboard and screen reader use. Nothing is uploaded: your numbers stay on your device.

1. Open [the one-sided puller in the Assistive Forge](https://openscad-assistive-forge.pages.dev/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). On a first visit Forge asks which interface you want: choose **Assistive Forge**, then **Download & Continue**, and it downloads its engine once.
2. Forge offers to keep a copy of the project in your browser. Choose **Save My Copy**: the tool is then listed on Forge's main page whenever you come back, no link needed.
3. The form shows the four steps' dials first. The rest sit behind one button, **Show all parameters**.

If the link cannot load, Forge says why and offers **Try again**. You can also download the whole tool as one file, [`dist/Plug_Puller_SingleFile.scad`](../../../dist/Plug_Puller_SingleFile.scad), and open it from Forge's main page, under Open or start a project.

### On your computer

OpenSCAD is the free program that turns your numbers into a printable file. You use one panel of it and never touch the code.

1. Download OpenSCAD from <https://openscad.org/downloads.html>: the **Development Snapshot** for your system. This project is tested with the snapshot of 2026-01-03; any recent snapshot works. The regular release works too, only slower.
2. Get the project: on its GitHub page press the green **Code** button, then **Download ZIP**, and unzip it anywhere. Or download only [`dist/Plug_Puller_SingleFile.scad`](../../../dist/Plug_Puller_SingleFile.scad), the whole tool in one file.
3. Open `src/Plug_Puller_Parametric.scad` (or the single file) in OpenSCAD: double-click it, or use **File ▸ Open**. A wall of code appears in an editor pane. Ignore it; you will not touch it.
4. Show the Customizer, the form you type into: in the **View** menu, make sure **Hide Customizer** is unchecked. In older versions it is **Window ▸ Customizer**.

The form's sections read top to bottom in the order you decide things: **Step 1 - Your Plug**, **Step 2 - Size**, **Step 3 - Attachment**, then **Step 4 - Cord Hook**. Everything below Step 4 is optional.

### Working in the browser

Forge and the desktop program show the same form and make the same tool. What differs:

- Forge draws the tool as it will print, with any red warning text beside it. It does not draw the see-through plug, or the green and orange notes of the desktop program's preview.
- A render takes longer in the browser than on the desktop, and longest on a phone. Forge says **Preview ready** under the picture when it is done.
- On a phone the screen is tight. The parameter search finds any dial by its name, and searching also brings back the dials behind **Show all parameters**.
- Forge can be installed as an app that works offline: use your browser's install button at the right end of the address bar.
- To send your numbers to someone, or to keep them, use Forge's **Copy Link**: the link carries the values you changed, and opening it puts them back.

| Problem | What to do |
| --- | --- |
| "The shared project could not be opened" | Forge names the reason. Press **Try again**; if it keeps failing, download the single file and open it from Forge's main page. |
| A dial you want is not on the form | Press **Show all parameters**. The four steps' dials are shown first; the rest sit behind that button. |
| Red text beside the tool in the preview | A measurement cannot work, and the text names it. Fix it before you export: the red text is part of the model. |

## Measure your plug and your hand

Everything here is in mm: a US plug is about 25 mm wide, so a 1 on your paper means you measured in inches. You need a caliper or a ruler with mm marks, the plug in its outlet, and your own hand only if you pick Measure my hand. Print the measuring form at 100 % and fill it in as you go: the sections below are the form's rows, in the same order, and the card names (R1, C1, F1 / F2) are the cards of the printed measuring stencil, described under Match a card instead of measuring.

### Plug length

Customizer name: `measure_plug_length`. Row 2 of the measuring form.

With the plug in the outlet, ruler from the wall plate face to the plug's back face. On a laptop or charger plug, measure from the device's edge.

Typical: 20 to 50 mm. Example: 38 mm.

With the stencil: card R1.

### Plug width at the prong end

Customizer name: `measure_plug_width_prong_end`. Row 3 of the measuring form.

Caliper straight across the plastic body just behind the prongs, the wide way, parallel to the wall. Measure the body, not the metal prongs; if the head flares, take the widest part of that first stretch.

Typical: 20 to 38 mm. Example: 34 mm.

With the stencil: card R1.

### Plug width at the cord end

Customizer name: `measure_plug_width_cord_end`. Row 4 of the measuring form.

The same wide direction, but where the cord leaves the plug body. Skip any soft rubber strain relief and measure the last part of the hard body you would grip.

Typical: 10 to 35 mm. Example: 13 mm.

With the stencil: card R1.

### Plug thickness at the prong end

Customizer name: `measure_plug_thickness_prong_end`. Row 5 of the measuring form.

Caliper across the plug body's thin direction, usually top to bottom on a flat plug, just behind the prongs. A plug 24 mm thick or more needs the two-sided puller, so measure carefully.

Typical: 12 to 30 mm. Example: 16 mm.

With the stencil: card R1.

### Plug thickness at the cord end

Customizer name: `measure_plug_thickness_cord_end`. Row 6 of the measuring form.

The same thin direction, where the cord leaves the plug body, skipping the soft strain relief. On a round extension-cord plug this can be as fat as the prong end.

Typical: 8 to 30 mm. Example: 9 mm.

With the stencil: card R1.

### Cord thickness

Customizer name: `measure_cord_thickness`. Row 7 of the measuring form.

Caliper across the cord just behind the plug, on its thin side: flat cord the narrow way, round cord the diameter. With the stencil, the smallest C1 slot that slips over the cord is this number.

Typical: 3 to 7 mm. Example: 5 mm.

With the stencil: card C1.

### Outlet cover plate style

Customizer name: `measure_wall_plate_style`. Row 8 of the measuring form.

Look at the outlet cover plate: two small oval openings is Standard flat plate; one big rectangle per outlet is Rocker / Decora; a bigger, thicker plate is Oversized / Jumbo; no plate or a flush outlet is No plate / flush.

The choices: Standard flat plate, Rocker / Decora, Oversized / Jumbo, No plate / flush.

### Finger width

Customizer name: `measure_finger_width`. Row 11 of the measuring form.

Caliper across the widest knuckle of your middle finger, the finger that goes into the pull hole. With the stencil, find the smallest F1 or F2 hole your finger passes through comfortably and subtract 5 from its number.

Typical: 16 to 24 mm. Example: 22 mm.

With the stencil: card F1 / F2.

No caliper? Take a ring that fits that finger snugly, measure the ring's inner diameter in mm and add 1.5 mm.

### Hand width

Customizer name: `measure_hand_width`. Row 12 of the measuring form.

Caliper or ruler straight across the four knuckles of your flat hand, fingers together, no thumb. Measure at the widest point.

Typical: 70 to 100 mm. Example: 88 mm.

With the stencil: card R1.

### Strap width

Customizer name: `strap_width`. Row 15 of the measuring form.

Read the width on the strap's packaging. ONE-WRAP comes in 10, 13, 16, 20 and 25 mm.

Typical: 10 to 25 mm. Example: 15 mm.

Sanity check: each plug width is a two-digit number, roughly 12 to 45, and the prong-end width is usually the bigger one; the finger width is roughly 14 to 32. A number like 1.3 is inches: measure again with the mm side.

When you measure for someone else, a relative or a client, measure their hand for the finger and hand rows and their outlet and plug for the plug rows. Doubtful between two values? Round up: a slightly roomy fit works, a tight one does not.

### The measuring form

The form is the sheet [measuring-form.svg](measuring-form.svg); the paper stencil sheets are [stencil-sheet.svg](../stencil-sheet.svg) and [stencil-sheet-2.svg](../stencil-sheet-2.svg). Print the form at 100 % (actual size, never fit to page) and check its 50 mm bar with a ruler before you trust it. Fill in the blanks top to bottom as you measure, then type the numbers into the Customizer in the same order.

| # | Customizer name | What you measure | Default | Yours |
|---|---|---|---|---|
| 1 | `plug_preset` | Plug preset: pick one | Measure my plug | ________ |
| 2 | `measure_plug_length` | With the plug in the outlet, ruler from the wall plate face to the plug's back face. | 25.5 mm | ________ |
| 3 | `measure_plug_width_prong_end` | Caliper straight across the plastic body just behind the prongs, the wide way, parallel to the wall. | 25 mm | ________ |
| 4 | `measure_plug_width_cord_end` | The same wide direction, but where the cord leaves the plug body. | 25 mm | ________ |
| 5 | `measure_plug_thickness_prong_end` | Caliper across the plug body's thin direction, usually top to bottom on a flat plug, just behind the prongs. | 20 mm | ________ |
| 6 | `measure_plug_thickness_cord_end` | The same thin direction, where the cord leaves the plug body, skipping the soft strain relief. | 20 mm | ________ |
| 7 | `measure_cord_thickness` | Caliper across the cord just behind the plug, on its thin side: flat cord the narrow way, round cord the diameter. | 4 mm | ________ |
| 8 | `measure_wall_plate_style` | Look at the outlet cover plate and pick the closest match. | Standard flat plate | ________ |
| 9 | `show_plug_preview` | Show the see-through plug: leave on | on | ________ |
| 10 | `size` | Hand size: pick one | Medium | ________ |
| 11 | `measure_finger_width` | Caliper across the widest knuckle of your middle finger, the finger that goes into the pull hole. | 20 mm | ________ |
| 12 | `measure_hand_width` | Caliper or ruler straight across the four knuckles of your flat hand, fingers together, no thumb. | 85 mm | ________ |
| 13 | `attachment` | Attachment: pick one | Zip ties + Velcro | ________ |
| 14 | `velcro_style` | Strap opening style: pick one | Wing | ________ |
| 15 | `strap_width` | Read the width on the strap's packaging. | 15 mm | ________ |
| 16 | `hook_hand` | Hook side: pick one | Right | ________ |

**What the sheet shows.** The left column is the numbered list above, one row per dial in the Customizer's Step order, each with the dial's name, its plain title and either a blank after the default or a tick box per choice with the default marked. The right half is a schematic plug in teal drawn from the one-sided puller's defaults at 1.5 to 1, a top view with the prong end at the left against a wall plate line, a side view standing with its prong end up, the cord's end as a small circle, a bar of four knuckles at 1:1 and a strap bar at 1:1. A straight black arrow runs from each measured row's blank to a red dimension line on the schematic, the row's number in a red circle at the line:

- Arrow 2 points to the plug's length on the top view, from the wall plate to the plug's back end.
- Arrow 3 points to the plug's width at the prong end, the left edge of the top view.
- Arrow 4 points to the plug's width at the cord end, the right edge of the top view where the cord leaves.
- Arrow 5 points to the plug's thickness at the prong end, the top of the side view.
- Arrow 6 points to the plug's thickness at the cord end, the bottom of the side view.
- Arrow 7 points to the cord's thickness on the small circle, the cord seen end on.
- Arrow 11 points to one knuckle of the knuckle bar, drawn 20 mm wide at 1:1.
- Arrow 12 points to the whole knuckle bar, four knuckles 85 mm across at 1:1.
- Arrow 15 points to the strap bar's width, a 40 by 15 mm bar at 1:1.

- Row 1, plug preset: 5 boxes, Measure my plug marked as the default; the choices are Measure my plug, Flat 2-prong lamp plug - NEMA 1-15, Standard 3-prong plug - NEMA 5-15, Heavy-duty extension cord - NEMA 5-15, Wide 2-prong appliance plug - NEMA 1-15.
- Row 8, outlet cover plate style: 4 boxes, Standard flat plate marked as the default; the choices are Standard flat plate, Rocker / Decora, Oversized / Jumbo, No plate / flush.
- Row 9, show the see-through plug: one box marked, leave on.
- Row 10, hand size: 5 boxes, Medium marked as the default; the choices are Small, Medium, Large, Measure my hand, Custom.
- Row 13, attachment: 4 boxes, Zip ties + Velcro marked as the default; the choices are Zip ties, Velcro strap, Zip ties + Velcro, None.
- Row 14, strap opening style: 2 boxes, Wing marked as the default; the choices are Wing, Classic slot.
- Row 16, hook side: 2 boxes, Right marked as the default; the choices are Right, Left.

Type them into the Customizer in this order.

### Match a card instead of measuring

The measuring stencil is a set of thin printed cards. Each has a two-letter name raised on its face, so you can find it by touch. Hold your plug in the plug cards: if it fills one card's openings, snug with no big gaps, that card names the preset to pick in Step 1, and you type no numbers at all.

| Card | What it is | What it answers |
| ---- | --- | --- |
| P1 | The flat 2-prong lamp plug (NEMA 1-15) | the preset `Flat 2-prong lamp plug - NEMA 1-15` |
| P2 | The standard 3-prong plug (NEMA 5-15) | the preset `Standard 3-prong plug - NEMA 5-15` |
| P3 | The heavy-duty extension cord plug (NEMA 5-15) | the two-sided puller's preset `Heavy-duty extension cord - NEMA 5-15` |
| P4 | The wide 2-prong appliance plug (NEMA 1-15) | the one-sided puller's preset `Wide 2-prong appliance plug - NEMA 1-15` |
| R1 | A ruler: raised mm ticks, numbers every 10 mm, and a notch every 10 mm you can count by touch | the plug's length, widths and thicknesses |
| C1 | A cord gauge: open slots 3 to 9 mm wide along one edge, slid onto the cord from the side | the cord thickness: the smallest slot that slips over the cord |
| F1, F2 | Finger holes 15 to 25 mm across (F1) and 26 to 32 mm (F2) | your finger width: the smallest hole your middle finger passes through comfortably, minus 5 |

Each P card has three openings: W for the plug's width, T for its thickness, and an open slot that slides onto the cord. If no card fits, your plug is between presets: measure it instead. The measured tool fits better than any preset.

**Printing the cards.** Print [`stl/Measuring-Stencil/Visual/Measuring-Stencil_Visual_All-Cards.stl`](../../../stl/Measuring-Stencil/Visual/Measuring-Stencil_Visual_All-Cards.stl): 1.2 mm thick cards, no supports, any rigid filament, packed onto sheets for a 200 by 200 mm bed. The tactile version, [`stl/Measuring-Stencil/Tactile/`](../../../stl/Measuring-Stencil/Tactile), prints every label as a raised character at ADA size and adds a Grade 2 braille title flap to every card.
Or print one card at a time from [`stl/Measuring-Stencil/`](../../../stl/Measuring-Stencil). For a smaller bed, open [`Measuring_Stencil.scad`](../../../Measuring_Stencil.scad) in OpenSCAD, set `bed_width` and `bed_depth` to your bed, and export `part_index` 1, then 2, and so on, one sheet at a time. `part_index` 0 previews every sheet at once; do not print that one.

**Folding the tactile flaps.** The tactile version is also `label_mode` set to Tactile in the file. Each flap prints leaning back, held by thin fins. Snap the fins off, then fold the flap away from the card until it lies flat, so the braille lands face up beyond the card's edge. Fold once, gently; a PETG or PP hinge folds more reliably than PLA.

**No 3D printer yet?** The last pages of the printed quick start and full guide are paper versions of the cards at true size: the plug outlines, a 100 mm ruler and the finger circles. Print them at 100 % (actual size, never fit to page) and check the 50 by 50 mm square with a ruler before you trust them. On their own they are [`stencil-sheet.svg`](../stencil-sheet.svg) and [`stencil-sheet-2.svg`](../stencil-sheet-2.svg).

### Try it on paper first

Every preset at every size has a printable sheet with the tool's exact outline at true size, its dimensions in mm, a 50 by 50 mm square to check the print scale, and the Customizer settings that make it. Print one at 100 % (actual size, never fit to page) and measure the square with a ruler: it must be exactly 50 by 50 mm, or the print was scaled. Cut out the outline along the solid line and poke through the two finger circles. Hold it against your plug on the wall: the plug should fit inside the dashed pocket outline, and the notch at the top edge should straddle the outlet cover. Try the finger holes; if they feel wrong, try the next size's sheet.

| Plug preset | Small | Medium | Large |
| --- | ----- | --- | ----- |
| Flat 2-prong lamp plug (NEMA 1-15) | [sheet](../outline-sheets/outline_flat-2-prong_small.svg) | [sheet](../outline-sheets/outline_flat-2-prong_medium.svg) | [sheet](../outline-sheets/outline_flat-2-prong_large.svg) |
| Standard 3-prong plug (NEMA 5-15) | [sheet](../outline-sheets/outline_standard-3-prong_small.svg) | [sheet](../outline-sheets/outline_standard-3-prong_medium.svg) | [sheet](../outline-sheets/outline_standard-3-prong_large.svg) |
| Wide 2-prong appliance plug (NEMA 1-15) | [sheet](../outline-sheets/outline_wide-2-prong-appliance_small.svg) | [sheet](../outline-sheets/outline_wide-2-prong-appliance_medium.svg) | [sheet](../outline-sheets/outline_wide-2-prong-appliance_large.svg) |

Every sheet, for both tools, is also in one printable PDF with an index: [`docs/Plug_Puller_Outline_Sheets.pdf`](../../Plug_Puller_Outline_Sheets.pdf). The sheets cover the presets only; a plug or a hand between sizes is better served by measuring.

## Step 1 - Your Plug

Pick a plug preset, or leave it on Measure my plug and type your plug's numbers.

### Plug preset

Customizer name: `plug_preset`

Fills in all six plug numbers from a measured reference plug, so the pocket, the wall notch, the cord hook and the zip-tie and wing positions all take that plug's shape at once.

Plug preset: before and after, Measure my plug to Standard 3-prong plug - NEMA 5-15; red marks 7 parts, named below.

Two top views of the one-sided puller, before left and after right, the plug end at the top. Left: the defaults, a 25 mm wide plug in teal. Right: plug preset set to Standard 3-prong plug - NEMA 5-15. Marked in red: 1, the zip-tie holes, the finger holes, the wing openings, the wall notch, the seat, the pocket and the body edge.

- Default: Measure my plug
- Choices: Measure my plug, Flat 2-prong lamp plug - NEMA 1-15, Standard 3-prong plug - NEMA 5-15, Heavy-duty extension cord - NEMA 5-15, Wide 2-prong appliance plug - NEMA 1-15
- Moves: body edge, finger holes, pocket, seat, wall notch, wing openings, zip-tie holes

### Plug length

Customizer name: `measure_plug_length`

Runs the pocket farther toward the finger holes and stretches the whole body to keep the finger holes and zip-tie rows clear of it.

Plug length: before and after, 25.5 to 40 mm; red marks the body edge, the seat, the wall notch, the wing openings and the zip-tie holes.

Two top views of the one-sided puller, before left and after right, the plug end at the top. Left: the defaults, a 25 mm wide plug in teal. Right: plug length at 40 mm. The red line marks the pocket's length and reads 40 mm, the number you type. Marked in red: 1, the zip-tie holes: the four small holes beside the pocket. 2, the zip-tie holes and the wing openings. 3, the zip-tie holes, the wing openings, the wall notch, the seat and the body edge.

- Default: 25.5 mm
- Range: 12 to 85 mm, in steps of 0.5 mm
- Moves: body edge, seat, wall notch, wing openings, zip-tie holes

### Plug width at the prong end

Customizer name: `measure_plug_width_prong_end`

Widens or narrows the pocket, its seat and the wall notch at the plug end, and moves the zip-tie holes and wing openings with them.

Plug width at the prong end: before and after, 25 to 32 mm; red marks 5 parts, named below.

Two top views of the one-sided puller, before left and after right, the plug end at the top. Left: the defaults, a 25 mm wide plug in teal. Right: plug width at the prong end at 32 mm. The red line marks the plug's width at the prong end and reads 32 mm, the number you type. Marked in red: 1, the zip-tie holes: the four small holes beside the pocket. 2, the wing openings: the two openings beside the pocket. 3, the wall notch, the seat and the body edge: the notch in the top edge; the round recess at the plug end; the outer outline.

- Default: 25 mm
- Range: 8 to 38 mm, in steps of 0.5 mm
- Moves: body edge, seat, wall notch, wing openings, zip-tie holes

### Plug width at the cord end

Customizer name: `measure_plug_width_cord_end`

Tilts the pocket's side walls to match the plug's taper, and the zip-tie holes and wing openings lean in with them.

Plug width at the cord end: before and after, 25 to 15 mm; red marks the pocket, the wing openings and the zip-tie holes.

Two top views of the one-sided puller, before left and after right, the plug end at the top. Left: the defaults, a 25 mm wide plug in teal. Right: plug width at the cord end at 15 mm. The red line marks the plug's width at the cord end and reads 15 mm, the number you type. Marked in red: 1, the zip-tie holes, the wing openings and the pocket: the four small holes beside the pocket; the two openings beside the pocket; the plug recess on the centerline.

- Default: 25 mm
- Range: 8 to 38 mm, in steps of 0.5 mm
- Moves: pocket, wing openings, zip-tie holes

### Plug thickness at the prong end

Customizer name: `measure_plug_thickness_prong_end`

Deepens or shallows the two pocket floors, the round seat and the plug recess, to suit the fatter of the two thickness numbers.

Plug thickness at the prong end: before and after, 20 to 23.5 mm; red marks the pocket and the seat.

Two vertical slices of the one-sided puller at x = 0 mm, before left and after right, the top face up. Left: the defaults, the plug in teal in the cut. Right: plug thickness at the prong end at 23.5 mm. The red line marks the plug's thickness at the prong end and reads 23.5 mm, the number you type. Marked in red: 1, the seat and the pocket: the round recess at the plug end; the plug recess on the centerline.

- Default: 20 mm
- Range: 4 to 40 mm, in steps of 0.5 mm
- Moves: pocket, seat

Note: The fatter of the two thickness numbers sets the floors, so lowering one alone changes nothing; 24 mm or more sends you to the two-sided puller.

### Plug thickness at the cord end

Customizer name: `measure_plug_thickness_cord_end`

Deepens or shallows the two pocket floors, the round seat and the plug recess, when this end is the fatter end of the plug.

Plug thickness at the cord end: before and after, 20 to 23.5 mm; red marks the pocket and the seat.

Two vertical slices of the one-sided puller at x = 0 mm, before left and after right, the top face up. Left: the defaults, the plug in teal in the cut. Right: plug thickness at the cord end at 23.5 mm. The red line marks the plug's thickness at the cord end and reads 23.5 mm, the number you type. Marked in red: 1, the seat and the pocket: the round recess at the plug end; the plug recess on the centerline.

- Default: 20 mm
- Range: 4 to 40 mm, in steps of 0.5 mm
- Moves: pocket, seat

Note: The fatter of the two thickness numbers sets the floors, so lowering one alone changes nothing; 24 mm or more sends you to the two-sided puller.

### Cord thickness

Customizer name: `measure_cord_thickness`

Widens the cord hook's slot and crossbar to fit the cord, and moves the finger holes and the whole body up to make room.

Cord thickness: before and after, 4 to 8 mm; red marks 6 parts, named below.

Two top views of the one-sided puller, before left and after right, the plug end at the top. Left: the defaults, a 25 mm wide plug in teal. Right: cord thickness at 8 mm. The red line marks the cord hook slot and reads 8 mm, the number you type; the slot is drawn 8.8 mm wide, so the cord slips in. Marked in red: 1, the zip-tie holes, the finger holes, the wing openings, the wall notch, the pocket and the body edge.

- Default: 4 mm
- Range: 1.5 to 9 mm, in steps of 0.5 mm
- Moves: body edge, finger holes, pocket, wall notch, wing openings, zip-tie holes

### Outlet cover plate style

Customizer name: `measure_wall_plate_style`

Cuts the wall notch at the plug end deeper or shallower to suit the cover plate, and the zip-tie rows shift down with it.

Outlet cover plate style: before and after, Standard flat plate to Oversized / Jumbo; red marks 5 parts, named below.

Two top views of the one-sided puller, before left and after right, the plug end at the top. Left: the defaults, a 25 mm wide plug in teal. Right: outlet cover plate style set to Oversized / Jumbo. Marked in red: 1, the wall notch and the body edge: the notch in the top edge; the outer outline. 2, the zip-tie holes: the four small holes beside the pocket. 3, the pocket: the plug recess on the centerline. 4, the wing openings: the two openings beside the pocket.

- Default: Standard flat plate
- Choices: Standard flat plate, Rocker / Decora, Oversized / Jumbo, No plate / flush
- Moves: body edge, pocket, wall notch, wing openings, zip-tie holes

### Show the see-through plug

Customizer name: `show_plug_preview`

Shows or hides the see-through plug in the preview and changes nothing in the printed tool.

No picture. Changes no shape: the see-through plug is a preview aid and is never exported.

- Default: On
- Choices: On or off (a check box)

## Step 2 - Size

Pick your hand size, or pick Measure my hand and type your hand's numbers.

### Hand size

Customizer name: `size`

Scales the whole body, both finger holes, the wing openings and the zip-tie grid to the chosen hand size.

Hand size: before and after, Medium to Large; red marks the body edge, the finger holes, the wall notch, the wing openings and the zip-tie holes.

Two top views of the one-sided puller, before left and after right, the plug end at the top. Left: the defaults, a 25 mm wide plug in teal. Right: hand size set to Large. Marked in red: 1, the zip-tie holes: the four small holes beside the pocket, removed. 2, the finger holes: the two large holes in the lower half. 3, the zip-tie holes, the wing openings, the wall notch and the body edge.

- Default: Medium
- Choices: Small, Medium, Large, Measure my hand, Custom
- Moves: body edge, finger holes, wall notch, wing openings, zip-tie holes

### Finger width

Customizer name: `measure_finger_width`

Widens both finger holes, spaces them farther apart and pushes them and the body up to keep the walls printable.

Finger width: before and after, 20 to 26 mm; red marks 7 parts, named below.

Two top views of the one-sided puller, before left and after right, the plug end at the top. Left: the defaults with hand size set to Measure my hand, a 25 mm wide plug in teal. Right: finger width at 26 mm. The red line marks a finger hole and reads 26 mm, the number you type; the hole is drawn 31.4 mm across, wider than the finger. Marked in red: 1, the zip-tie holes, the finger holes, the wing openings, the wall notch, the seat, the pocket and the body edge.

- Default: 20 mm
- Range: 14 to 32 mm, in steps of 0.5 mm
- Moves: body edge, finger holes, pocket, seat, wall notch, wing openings, zip-tie holes

Note: Only acts when size is Measure my hand.

### Hand width

Customizer name: `measure_hand_width`

Widens the whole body outline and thickens the slab in step with the hand.

Hand width: before and after, 85 to 100 mm; red marks the body edge and the wing openings.

Two top views of the one-sided puller, before left and after right, the plug end at the top. Left: the defaults with hand size set to Measure my hand, a 25 mm wide plug in teal. Right: hand width at 100 mm. The red line marks the body at its widest and reads 100 mm, the number you type; the body is drawn 80.3 mm wide, narrower than the hand, as its width is worked out from the hand width. Marked in red: 1, the wing openings and the body edge: the two openings beside the pocket; the outer outline.

- Default: 85 mm
- Range: 60 to 110 mm, in steps of 1 mm
- Moves: body edge, wing openings

Note: Only acts when size is Measure my hand.

## Step 3 - Attachment

Pick how the tool attaches.

### Attachment

Customizer name: `attachment`

Adds or removes the zip-tie holes and the wing or slot openings for the strap.

Attachment: before and after, Zip ties + Velcro to Zip ties; red marks the wing openings.

Two top views of the one-sided puller, before left and after right, the plug end at the top. Left: the defaults, a 25 mm wide plug in teal. Right: attachment set to Zip ties. Marked in red: 1, the wing openings: the two openings beside the pocket, removed. The body edge, the pocket, the seat and the wall notch stay where they were.

- Default: Zip ties + Velcro
- Choices: Zip ties, Velcro strap, Zip ties + Velcro, None
- Moves: wing openings

### Strap opening style

Customizer name: `velcro_style`

Swaps the curved wing openings for a pair of plain rectangular slots that lean along the body's sides.

Strap opening style: before and after, Wing to Classic slot; red marks the classic slots and the wing openings.

Two top views of the one-sided puller, before left and after right, the plug end at the top. Left: the defaults, a 25 mm wide plug in teal. Right: strap opening style set to Classic slot. Marked in red: 1, the wing openings and the classic slots: the two openings beside the pocket; the two slots beside the pocket.

- Default: Wing
- Choices: Wing, Classic slot
- Moves: classic slots, wing openings
- Red warnings: WING OPENING SMALLER THAN STRAP WIDTH

### Strap width

Customizer name: `strap_width`

Sets the strap width the wing opening is checked against and changes no shape.

No picture. Changes no shape: it only sets the width the W-14 check compares the wing opening against.

- Default: 15 mm
- Range: 10 to 25 mm, in steps of 1 mm
- Red warnings: WING OPENING SMALLER THAN STRAP WIDTH; WING WEB COLLAPSED - NO ROOM FOR STRAP

## Step 4 - Cord Hook

Pick the hook's side.

### Hook side

Customizer name: `hook_hand`

Mirrors the cord hook at the cord end so its catch faces the other side, and nothing else moves.

Hook side: before and after, Right to Left; red marks the hook.

Two top views of the one-sided puller, before left and after right, the plug end at the top. Left: the defaults, a 25 mm wide plug in teal. Right: hook side set to Left. Marked in red: 1, the hook: the cord hook slot in the bottom edge. The body edge, the pocket, the seat and the wall notch stay where they were.

- Default: Right
- Choices: Right, Left
- Moves: hook

## The optional dials

Everything below Step 4 in the Customizer is optional. These dials apply in every hand size, except the sections marked (Custom size only), which do nothing until Step 2's hand size is Custom. The sections follow in the Customizer's order; how they work together is explained after the troubleshooting sections.

- **Advanced - Zip Tie Placement**, 6 dials: Zip-tie hole placement, Number of zip-tie rows, Zip-tie pair 1 position, Zip-tie pair 2 position, Zip-tie pair 3 position, Zip-tie hole distance from the pocket wall.
- **Advanced - Velcro Placement**, 2 dials: Strap slot placement, Strap slot position.
- **Advanced - Render Quality**, 1 dial: Render quality.
- **Custom Mode**, 2 dials: Reset Custom to the Medium reference, Auto-fit.
- **Body Shape (Custom size only)**, 8 dials: Body length, Body width at the widest point, Cord-end corner width, Body width at the plug end, Body width at the middle, Side corner position, Body thickness, Round the cord half only.
- **Plug Pocket (Custom size only)**, 7 dials: Pocket seat diameter, Pocket width, Pocket depth, Pocket reference drop, Pocket seat floor thickness, Plug recess floor thickness, Pocket side taper.
- **Finger Holes (Custom size only)**, 4 dials: Finger holes on or off, Finger hole diameter, Finger hole spacing, Finger hole position.
- **T Hook (Custom size only)**, 10 dials: Cord hook on or off, Hook slot width, Hook length, Hook crossbar width, Hook crossbar height, Hook slot inset, Hook stem side offset, Hook stem offset, Hook catch reach, Hook tip drop.
- **Plug Wall Notch (Custom size only)**, 4 dials: Wall notch on or off, Wall notch width, Wall notch depth, Wall notch corner rounding.
- **Zip Tie Holes (Custom size only)**, 5 dials: Zip-tie hole diameter, Zip-tie row spacing, Zip-tie column spacing, Zip-tie distance from the notch, Zip-tie countersink.
- **Velcro / Wing Strap Holes (Custom size only)**, 5 dials: Strap slot length, Strap slot width, Strap slot distance from the centerline, Strap slot position along the body, Strap slot lean.
- **Edge Rounding (Custom size only)**, 9 dials: Body side rounding, Top edge rounding, Bottom edge rounding, Strap slot corner rounding, Strap opening edge rounding, Finger hole rim rounding, Hook crossbar corner rounding, Hook slot corner rounding, Hook edge rounding.

## Advanced - Zip Tie Placement

### Zip-tie hole placement

Customizer name: `zip_placement`

Switches the zip-tie pairs from the automatic rows to the three position dials, which slide each pair along the plug's side.

Zip-tie hole placement: before and after, Auto to Manual; red marks the seat, the wall notch, the wing openings and the zip-tie holes.

Two top views of the one-sided puller, before left and after right, the plug end at the top. Left: the defaults, a 25 mm wide plug in teal. Right: zip-tie hole placement set to Manual. Marked in red: 1, the zip-tie holes, the wall notch and the seat: the four small holes beside the pocket; the notch in the top edge; the round recess at the plug end. 2, the wing openings: the two openings beside the pocket. 3, the zip-tie holes: the four small holes beside the pocket.

- Default: Auto
- Choices: Auto, Manual
- Moves: seat, wall notch, wing openings, zip-tie holes

### Number of zip-tie rows

Customizer name: `zip_row_count`

Adds or removes a pair of zip-tie holes, and the rows squeeze together when the body has no room for another.

Number of zip-tie rows: before and after, 2 to 3; red marks the wing openings and the zip-tie holes.

Two top views of the one-sided puller, before left and after right, the plug end at the top. Left: the defaults, a 25 mm wide plug in teal. Right: number of zip-tie rows at 3. Marked in red: 1, the wing openings: the two openings beside the pocket. 2, the zip-tie holes: the four small holes beside the pocket.

- Default: 2
- Range: 1 to 3, in steps of 1
- Moves: wing openings, zip-tie holes

### Zip-tie pair 1 position

Customizer name: `zip_pos_1`

Slides the first pair of zip-tie holes along the plug's side, measured from the plug end.

Zip-tie pair 1 position: before and after, 6 to 10 mm; red marks the seat, the wall notch and the zip-tie holes.

Two top views of the one-sided puller, before left and after right, the plug end at the top. Left: the defaults with zip-tie hole placement set to Manual, a 25 mm wide plug in teal. Right: zip-tie pair 1 position at 10 mm. Marked in red: 1, the zip-tie holes, the wall notch and the seat: the four small holes beside the pocket; the notch in the top edge; the round recess at the plug end.

- Default: 6 mm
- Range: 0 to 55 mm, in steps of 0.5 mm
- Moves: seat, wall notch, zip-tie holes
- Red warnings: ZIP TIE HOLES HIT FINGER HOLES; ZIP TIE ROWS OVERLAP EACH OTHER; ZIP TIE HOLES HIT VELCRO SLOTS

Note: Only acts when zip_placement is Manual.

### Zip-tie pair 2 position

Customizer name: `zip_pos_2`

Slides the second pair of zip-tie holes along the plug's side, measured from the plug end.

Zip-tie pair 2 position: before and after, 18 to 26 mm; red marks the wing openings and the zip-tie holes.

Two top views of the one-sided puller, before left and after right, the plug end at the top. Left: the defaults with zip-tie hole placement set to Manual, a 25 mm wide plug in teal. Right: zip-tie pair 2 position at 26 mm. Marked in red: 1, the zip-tie holes: the four small holes beside the pocket. 2, the wing openings: the two openings beside the pocket.

- Default: 18 mm
- Range: 0 to 55 mm, in steps of 0.5 mm
- Moves: wing openings, zip-tie holes
- Red warnings: ZIP TIE HOLES HIT FINGER HOLES; ZIP TIE ROWS OVERLAP EACH OTHER; ZIP TIE HOLES HIT VELCRO SLOTS

Note: Only acts when zip_placement is Manual.

### Zip-tie pair 3 position

Customizer name: `zip_pos_3`

Slides the third pair of zip-tie holes along the plug's side, measured from the plug end.

Zip-tie pair 3 position: before and after, 30 to 26 mm; red marks the wing openings and the zip-tie holes.

Two top views of the one-sided puller, before left and after right, the plug end at the top. Left: the defaults with zip-tie hole placement set to Manual and number of zip-tie rows set to 3, a 25 mm wide plug in teal. Right: zip-tie pair 3 position at 26 mm. Marked in red: 1, the wing openings: the two openings beside the pocket. 2, the zip-tie holes and the wing openings: the four small holes beside the pocket; the two openings beside the pocket.

- Default: 30 mm
- Range: 0 to 55 mm, in steps of 0.5 mm
- Moves: wing openings, zip-tie holes
- Red warnings: ZIP TIE HOLES HIT FINGER HOLES; ZIP TIE ROWS OVERLAP EACH OTHER; ZIP TIE HOLES HIT VELCRO SLOTS

Note: Only acts when zip_placement is Manual and zip_row_count is 3.

### Zip-tie hole distance from the pocket wall

Customizer name: `zip_edge_offset`

Moves every zip-tie hole farther from or closer to the pocket wall, and the wing openings reshape around them.

Zip-tie hole distance from the pocket wall: before and after, 4 to 8 mm; red marks the wing openings and the zip-tie holes.

Two top views of the one-sided puller, before left and after right, the plug end at the top. Left: the defaults, a 25 mm wide plug in teal. Right: zip-tie hole distance from the pocket wall at 8 mm. Marked in red: 1, the zip-tie holes: the four small holes beside the pocket. 2, the wing openings: the two openings beside the pocket.

- Default: 4 mm
- Range: 2.5 to 12 mm, in steps of 0.25 mm
- Moves: wing openings, zip-tie holes

## Advanced - Velcro Placement

### Strap slot placement

Customizer name: `velcro_placement`

Switches the strap openings to a pair of plain slots that the position dial slides along the plug's side, whatever the opening style.

Strap slot placement: before and after, Auto to Manual; red marks the wing openings.

Two top views of the one-sided puller, before left and after right, the plug end at the top. Left: the defaults, a 25 mm wide plug in teal. Right: strap slot placement set to Manual. Marked in red: 1, the wing openings: the two openings beside the pocket. The body edge, the pocket, the seat and the wall notch stay where they were.

- Default: Auto
- Choices: Auto, Manual
- Moves: wing openings

### Strap slot position

Customizer name: `velcro_pos`

Slides the pair of strap slots along the plug's side, measured from the plug end.

Strap slot position: before and after, 12 to 25 mm; red marks the classic slots.

Two top views of the one-sided puller, before left and after right, the plug end at the top. Left: the defaults with strap opening style set to Classic slot and strap slot placement set to Manual, a 25 mm wide plug in teal. Right: strap slot position at 25 mm. Marked in red: 1, the classic slots: the two slots beside the pocket.

- Default: 12 mm
- Range: 0 to 55 mm, in steps of 0.5 mm
- Moves: classic slots
- Red warnings: ZIP TIE HOLES HIT VELCRO SLOTS

Note: Only acts when velcro_placement is Manual.

## Advanced - Render Quality

### Render quality

Customizer name: `quality`

Sets how many flat segments draw each curve and changes no dimension.

No picture. Changes no shape: it only sets the number of segments in every circle and arc.

- Default: 64 segments
- Range: 24 to 128 segments, in steps of 8 segments

## Custom Mode

### Reset Custom to the Medium reference

Customizer name: `reset_custom_to_medium`

Swaps every Custom slider for the Medium reference values for one render, so the whole tool snaps back to the Medium shape.

Reset Custom to the Medium reference: before and after, false to true; red marks 4 parts, named below.

Two top views of the one-sided puller, before left and after right, the plug end at the top. Left: the defaults with hand size set to Custom, a 25 mm wide plug in teal. Right: reset Custom to the Medium reference set to true. Marked in red: 1, the zip-tie holes: the four small holes beside the pocket. 2, the wing openings: the two openings beside the pocket. 3, the finger holes: the two large holes in the lower half. 4, the zip-tie holes and the body edge.

- Default: Off
- Choices: On or off (a check box)
- Moves: body edge, finger holes, wing openings, zip-tie holes

Note: Only acts when size is Custom.

### Auto-fit

Customizer name: `custom_enable_auto_fit`

Lets the tool clamp any Custom slider that would push a feature past the body or into a neighbor, and changes nothing while every slider is inside its safe range.

No picture. Changes no shape at the Custom defaults: it only clamps sliders that leave their safe range, and every clamp is reported in the console.

- Default: On
- Choices: On or off (a check box)
- Red warnings: ZIP TIE HOLES HIT FINGER HOLES; FINGER HOLES OUTSIDE BODY; POCKET SEAT WIDER THAN TOP EDGE; POCKET WIDER THAN BODY; WALL NOTCH WIDER THAN TOP EDGE

## Body Shape (Custom size only)

### Body length

Customizer name: `custom_puller_length`

Stretches the whole body from the cord end to the plug end.

Body length: before and after, 63.5 to 73.5 mm; red marks 6 parts, named below.

Two top views of the one-sided puller, before left and after right, the plug end at the top. Left: the defaults with hand size set to Custom, a 25 mm wide plug in teal. Right: body length at 73.5 mm. Marked in red: 1, the zip-tie holes, the wing openings, the wall notch, the seat, the pocket and the body edge.

- Default: 63.5 mm
- Range: 50 to 120 mm, in steps of 0.5 mm
- Moves: body edge, pocket, seat, wall notch, wing openings, zip-tie holes

Note: Only acts when size is Custom.

### Body width at the widest point

Customizer name: `custom_puller_bottom_width`

Widens the body at its widest point, just above the cord end, before the side rounding is applied.

Body width at the widest point: before and after, 77.6 to 87.6 mm; red marks the body edge.

Two top views of the one-sided puller, before left and after right, the plug end at the top. Left: the defaults with hand size set to Custom, a 25 mm wide plug in teal. Right: body width at the widest point at 87.6 mm. Marked in red: 1, the body edge: the outer outline. Everything else follows the outline.

- Default: 77.6 mm
- Range: 50 to 120 mm, in steps of 0.05 mm
- Moves: body edge

Note: Only acts when size is Custom.

### Cord-end corner width

Customizer name: `custom_puller_bottom_corners`

Widens the flat at the cord end where the two lower corners of the body outline sit.

Cord-end corner width: before and after, 3 to 13 mm; red marks the body edge.

Two top views of the one-sided puller, before left and after right, the plug end at the top. Left: the defaults with hand size set to Custom, a 25 mm wide plug in teal. Right: cord-end corner width at 13 mm. Marked in red: 1, the body edge: the outer outline. Everything else follows the outline.

- Default: 3 mm
- Range: 3 to 80 mm, in steps of 0.25 mm
- Moves: body edge

Note: Only acts when size is Custom.

### Body width at the plug end

Customizer name: `custom_puller_top_width`

Widens the plug end of the body, where the wall notch and the pocket seat sit.

Body width at the plug end: before and after, 31.75 to 41.75 mm; red marks the body edge and the wing openings.

Two top views of the one-sided puller, before left and after right, the plug end at the top. Left: the defaults with hand size set to Custom, a 25 mm wide plug in teal. Right: body width at the plug end at 41.75 mm. Marked in red: 1, the body edge: the outer outline. 2, the wing openings: the two openings beside the pocket. Everything else follows the outline.

- Default: 31.75 mm
- Range: 25 to 80 mm, in steps of 0.25 mm
- Moves: body edge, wing openings

Note: Only acts when size is Custom.

### Body width at the middle

Customizer name: `custom_puller_middle_width`

Widens the body at the middle control point, bulging or straightening the side edges between the widest point and the plug end.

Body width at the middle: before and after, 57.35 to 67.35 mm; red marks the body edge and the wing openings.

Two top views of the one-sided puller, before left and after right, the plug end at the top. Left: the defaults with hand size set to Custom, a 25 mm wide plug in teal. Right: body width at the middle at 67.35 mm. Marked in red: 1, the body edge: the outer outline. 2, the wing openings: the two openings beside the pocket. Everything else follows the outline.

- Default: 57.35 mm
- Range: 25 to 120 mm, in steps of 0.05 mm
- Moves: body edge, wing openings

Note: Only acts when size is Custom.

### Side corner position

Customizer name: `custom_puller_side_corner`

Moves the two widest corners of the body outline up toward the plug end or down toward the cord end.

Side corner position: before and after, 4.65 to 14.65 mm; red marks the body edge and the wing openings.

Two top views of the one-sided puller, before left and after right, the plug end at the top. Left: the defaults with hand size set to Custom, a 25 mm wide plug in teal. Right: side corner position at 14.65 mm. Marked in red: 1, the wing openings: the two openings beside the pocket. 2, the body edge: the outer outline. Everything else follows the outline.

- Default: 4.65 mm
- Range: 3 to 35 mm, in steps of 0.05 mm
- Moves: body edge, wing openings

Note: Only acts when size is Custom.

### Body thickness

Customizer name: `custom_body_thickness`

Thickens the whole slab, so every hole and the pocket get deeper walls.

Body thickness: before and after, 6.35 to 9 mm; red marks the body edge.

Two vertical slices of the one-sided puller at y = 35 mm, before left and after right, the top face up. Left: the defaults with hand size set to Custom, the plug in teal in the cut. Right: body thickness at 9 mm. Marked in red: 1, the body edge: the outer outline. Everything else follows the outline.

- Default: 6.35 mm
- Range: 4 to 15 mm, in steps of 0.05 mm
- Moves: body edge

Note: Only acts when size is Custom.

### Round the cord half only

Customizer name: `custom_body_round_bottom_only`

Rounds the whole outline instead of only the cord half, so the plug end loses its crisp corners.

Round the cord half only: before and after, true to false; red marks the body edge, the hook, the seat and the wall notch.

Two top views of the one-sided puller, before left and after right, the plug end at the top. Left: the defaults with hand size set to Custom, a 25 mm wide plug in teal. Right: round the cord half only set to false. Marked in red: 1, the wall notch and the seat: the notch in the top edge; the round recess at the plug end.

- Default: On
- Choices: On or off (a check box)
- Moves: body edge, hook, seat, wall notch

Note: Only acts when size is Custom.

## Plug Pocket (Custom size only)

### Pocket seat diameter

Customizer name: `custom_pocket_seat_diameter`

Widens the round seat cut into the plug end of the pocket.

Pocket seat diameter: before and after, 31.75 to 28 mm; red marks the seat.

Two top views of the one-sided puller, before left and after right, the plug end at the top. Left: the defaults with hand size set to Custom, a 25 mm wide plug in teal. Right: pocket seat diameter at 28 mm. Marked in red: 1, the seat: the round recess at the plug end. The body edge, the pocket, the wall notch and the wing openings stay where they were.

- Default: 31.75 mm
- Range: 10 to 45 mm, in steps of 0.05 mm
- Moves: seat

Note: Only acts when size is Custom.

### Pocket width

Customizer name: `custom_pocket_width`

Widens the plug recess, and the zip-tie holes and wing openings move outward with its wall.

Pocket width: before and after, 28.85 to 34 mm; red marks the pocket, the seat, the wing openings and the zip-tie holes.

Two top views of the one-sided puller, before left and after right, the plug end at the top. Left: the defaults with hand size set to Custom, a 25 mm wide plug in teal. Right: pocket width at 34 mm. Marked in red: 1, the seat and the pocket: the round recess at the plug end; the plug recess on the centerline. 2, the zip-tie holes: the four small holes beside the pocket. 3, the wing openings: the two openings beside the pocket.

- Default: 28.85 mm
- Range: 10 to 45 mm, in steps of 0.05 mm
- Moves: pocket, seat, wing openings, zip-tie holes

Note: Only acts when size is Custom.

### Pocket depth

Customizer name: `custom_pocket_depth`

Runs the plug recess farther from the plug end toward the finger holes.

Pocket depth: before and after, 24.5 to 34 mm; red marks the pocket and the wing openings.

Two top views of the one-sided puller, before left and after right, the plug end at the top. Left: the defaults with hand size set to Custom, a 25 mm wide plug in teal. Right: pocket depth at 34 mm. Marked in red: 1, the pocket: the plug recess on the centerline. 2, the wing openings: the two openings beside the pocket.

- Default: 24.5 mm
- Range: 5 to 60 mm, in steps of 0.5 mm
- Moves: pocket, wing openings

Note: Only acts when size is Custom.

### Pocket reference drop

Customizer name: `custom_pocket_dome_drop`

Changes no shape of the pocket, because the recess outline is built from the plug width at the plug end and the side taper, and this reference point cancels out of it.

No picture. Changes no shape: the recess is a rounded-nose shape whose width at the plug end is the pocket width and whose walls follow the side taper, so this reference point cancels out; measured with straight and with tapered walls.

- Default: 2.15 mm
- Range: 0 to 8 mm, in steps of 0.05 mm

### Pocket seat floor thickness

Customizer name: `custom_pocket_seat_floor`

Thins or thickens the floor left under the round seat, so the seat is cut deeper or shallower.

Pocket seat floor thickness: before and after, 3.175 to 1.5 mm; red marks the seat.

Two vertical slices of the one-sided puller at x = 0 mm, before left and after right, the top face up. Left: the defaults with hand size set to Custom, the plug in teal in the cut. Right: pocket seat floor thickness at 1.5 mm. Marked in red: 1, the seat: the round recess at the plug end.

- Default: 3.175 mm
- Range: 0 to 8 mm, in steps of 0.025 mm
- Moves: seat

Note: Only acts when size is Custom.

### Plug recess floor thickness

Customizer name: `custom_pocket_floor`

Thins or thickens the floor left under the plug recess, so the recess is cut deeper or shallower.

Plug recess floor thickness: before and after, 3.81 to 2 mm; red marks the pocket and the seat.

Two vertical slices of the one-sided puller at x = 0 mm, before left and after right, the top face up. Left: the defaults with hand size set to Custom, the plug in teal in the cut. Right: plug recess floor thickness at 2 mm. Marked in red: 1, the seat and the pocket: the round recess at the plug end; the plug recess on the centerline.

- Default: 3.81 mm
- Range: 0 to 12 mm, in steps of 0.025 mm
- Moves: pocket, seat

Note: Only acts when size is Custom.

### Pocket side taper

Customizer name: `custom_pocket_side_angle`

Tilts the pocket's side walls inward toward the cord end, and the zip-tie holes and strap slots lean in along the same line.

Pocket side taper: before and after, 0 to 10 mm; red marks the pocket, the wing openings and the zip-tie holes.

Two top views of the one-sided puller, before left and after right, the plug end at the top. Left: the defaults with hand size set to Custom, a 25 mm wide plug in teal. Right: pocket side taper at 10 mm. Marked in red: 1, the zip-tie holes, the wing openings and the pocket: the four small holes beside the pocket; the two openings beside the pocket; the plug recess on the centerline.

- Default: 0 mm
- Range: -15 to 25 mm, in steps of 0.5 mm
- Moves: pocket, wing openings, zip-tie holes

Note: Only acts when size is Custom.

## Finger Holes (Custom size only)

### Finger holes on or off

Customizer name: `custom_enable_finger_holes`

Cuts or leaves out both finger holes.

Finger holes on or off: before and after, true to false; red marks the body edge and the finger holes.

Two top views of the one-sided puller, before left and after right, the plug end at the top. Left: the defaults with hand size set to Custom, a 25 mm wide plug in teal. Right: finger holes on or off set to false. Marked in red: 1, the finger holes and the body edge: the two large holes in the lower half; the outer outline, removed. Everything else follows the outline.

- Default: On
- Choices: On or off (a check box)
- Moves: body edge, finger holes

Note: Only acts when size is Custom.

### Finger hole diameter

Customizer name: `custom_finger_hole_diameter`

Widens both finger holes.

Finger hole diameter: before and after, 25.4 to 22 mm; red marks the finger holes and the wing openings.

Two top views of the one-sided puller, before left and after right, the plug end at the top. Left: the defaults with hand size set to Custom, a 25 mm wide plug in teal. Right: finger hole diameter at 22 mm. Marked in red: 1, the wing openings: the two openings beside the pocket. 2, the finger holes: the two large holes in the lower half. The body edge, the pocket, the seat and the wall notch stay where they were.

- Default: 25.4 mm
- Range: 15 to 40 mm, in steps of 0.1 mm
- Moves: finger holes, wing openings

Note: Only acts when size is Custom.

### Finger hole spacing

Customizer name: `custom_finger_hole_spacing`

Moves the two finger holes farther apart or closer together.

Finger hole spacing: before and after, 33 to 40 mm; red marks the finger holes and the wing openings.

Two top views of the one-sided puller, before left and after right, the plug end at the top. Left: the defaults with hand size set to Custom, a 25 mm wide plug in teal. Right: finger hole spacing at 40 mm. Marked in red: 1, the wing openings: the two openings beside the pocket. 2, the finger holes: the two large holes in the lower half.

- Default: 33 mm
- Range: 20 to 50 mm, in steps of 0.5 mm
- Moves: finger holes, wing openings

Note: Only acts when size is Custom.

### Finger hole position

Customizer name: `custom_finger_hole_y_position`

Slides both finger holes up toward the pocket or down toward the cord hook.

Finger hole position: before and after, 19.8 to 26 mm; red marks the finger holes, the pocket, the wing openings and the zip-tie holes.

Two top views of the one-sided puller, before left and after right, the plug end at the top. Left: the defaults with hand size set to Custom, a 25 mm wide plug in teal. Right: finger hole position at 26 mm. Marked in red: 1, the zip-tie holes and the pocket. 2, the zip-tie holes, the finger holes and the wing openings.

- Default: 19.8 mm
- Range: 10 to 50 mm, in steps of 0.1 mm
- Moves: finger holes, pocket, wing openings, zip-tie holes

Note: Only acts when size is Custom.

## T Hook (Custom size only)

### Cord hook on or off

Customizer name: `custom_enable_t_hook`

Cuts or leaves out the cord hook at the cord end.

Cord hook on or off: before and after, true to false; red marks the hook.

Two top views of the one-sided puller, before left and after right, the plug end at the top. Left: the defaults with hand size set to Custom, a 25 mm wide plug in teal. Right: cord hook on or off set to false. Marked in red: 1, the hook: the cord hook slot in the bottom edge. The body edge, the pocket, the seat and the wall notch stay where they were.

- Default: On
- Choices: On or off (a check box)
- Moves: hook

Note: Only acts when size is Custom.

### Hook slot width

Customizer name: `custom_t_hook_base_gap`

Widens the slot the cord slides into at the cord end.

Hook slot width: before and after, 4.7625 to 7 mm; red marks the hook.

Two top views of the one-sided puller, before left and after right, the plug end at the top. Left: the defaults with hand size set to Custom, a 25 mm wide plug in teal. Right: hook slot width at 7 mm. Marked in red: 1, the hook: the cord hook slot in the bottom edge. The body edge, the pocket, the seat and the wall notch stay where they were.

- Default: 4.7625 mm
- Range: 3 to 10 mm, in steps of 0.05 mm
- Moves: hook

Note: Only acts when size is Custom.

### Hook length

Customizer name: `custom_t_hook_length`

Runs the cord hook farther into the body from the cord end.

Hook length: before and after, 10.16 to 15 mm; red marks the finger holes, the hook, the pocket, the wing openings and the zip-tie holes.

Two top views of the one-sided puller, before left and after right, the plug end at the top. Left: the defaults with hand size set to Custom, a 25 mm wide plug in teal. Right: hook length at 15 mm. Marked in red: 1, the finger holes: the two large holes in the lower half. 2, the finger holes and the hook: the two large holes in the lower half; the cord hook slot in the bottom edge.

- Default: 10.16 mm
- Range: 6 to 20 mm, in steps of 0.05 mm
- Moves: finger holes, hook, pocket, wing openings, zip-tie holes

Note: Only acts when size is Custom.

### Hook crossbar width

Customizer name: `custom_t_hook_holder_width`

Widens the crossbar the cord hooks under at the top of the slot.

Hook crossbar width: before and after, 11.1125 to 16 mm; red marks the finger holes, the hook, the wing openings and the zip-tie holes.

Two top views of the one-sided puller, before left and after right, the plug end at the top. Left: the defaults with hand size set to Custom, a 25 mm wide plug in teal. Right: hook crossbar width at 16 mm. Marked in red: 1, the finger holes and the hook: the two large holes in the lower half; the cord hook slot in the bottom edge. 2, the finger holes: the two large holes in the lower half.

- Default: 11.1125 mm
- Range: 8 to 25 mm, in steps of 0.05 mm
- Moves: finger holes, hook, wing openings, zip-tie holes

Note: Only acts when size is Custom.

### Hook crossbar height

Customizer name: `custom_t_hook_holder_length`

Makes the crossbar opening taller or shorter along the body.

Hook crossbar height: before and after, 5.08 to 8 mm; red marks the hook.

Two top views of the one-sided puller, before left and after right, the plug end at the top. Left: the defaults with hand size set to Custom, a 25 mm wide plug in teal. Right: hook crossbar height at 8 mm. Marked in red: 1, the hook: the cord hook slot in the bottom edge. The body edge, the pocket, the seat and the wall notch stay where they were.

- Default: 5.08 mm
- Range: 2 to 15 mm, in steps of 0.05 mm
- Moves: hook

Note: Only acts when size is Custom.

### Hook slot inset

Customizer name: `custom_t_hook_gap_offset`

Changes no shape of the printed tool, because the J-hook cord catch does not read this dial.

No picture. Changes no shape: the J-hook cord catch is drawn without this dial; it only appears in the Cutouts Only 2D debug overlay.

- Default: 0 mm
- Range: 0 to 8 mm, in steps of 0.5 mm

### Hook stem side offset

Customizer name: `custom_t_hook_leg_offset`

Moves nothing on the hook itself, and only pushes the finger holes up when the auto-fit keep-out around the hook grows with it.

Hook stem side offset: before and after, 0 to 3 mm; red marks the finger holes, the wing openings and the zip-tie holes.

Two top views of the one-sided puller, before left and after right, the plug end at the top. Left: the defaults with hand size set to Custom, a 25 mm wide plug in teal. Right: hook stem side offset at 3 mm. Marked in red: 1, the wing openings: the two openings beside the pocket. 2, the zip-tie holes: the four small holes beside the pocket. 3, the finger holes: the two large holes in the lower half.

- Default: 0 mm
- Range: -5 to 5 mm, in steps of 0.5 mm
- Moves: finger holes, wing openings, zip-tie holes

Note: Only acts when size is Custom; the J-hook cord catch is drawn without this dial, and only the auto-fit clamp on the finger holes reads it.

### Hook stem offset

Customizer name: `custom_t_hook_stem_offset`

Shifts the cord slot sideways along the crossbar, making the J of the hook deeper or shallower.

Hook stem offset: before and after, 4.5 to 7 mm; red marks the hook.

Two top views of the one-sided puller, before left and after right, the plug end at the top. Left: the defaults with hand size set to Custom, a 25 mm wide plug in teal. Right: hook stem offset at 7 mm. Marked in red: 1, the hook: the cord hook slot in the bottom edge. The body edge, the pocket, the seat and the wall notch stay where they were.

- Default: 4.5 mm
- Range: 0 to 8 mm, in steps of 0.05 mm
- Moves: hook

Note: Only acts when size is Custom.

### Hook catch reach

Customizer name: `custom_t_hook_catch_reach`

Extends the crossbar past the slot on the catch side, lengthening the lip the cord hooks under.

Hook catch reach: before and after, 4.55 to 8 mm; red marks the hook.

Two top views of the one-sided puller, before left and after right, the plug end at the top. Left: the defaults with hand size set to Custom, a 25 mm wide plug in teal. Right: hook catch reach at 8 mm. Marked in red: 1, the hook: the cord hook slot in the bottom edge. The body edge, the pocket, the seat and the wall notch stay where they were.

- Default: 4.55 mm
- Range: 0 to 10 mm, in steps of 0.05 mm
- Moves: hook

Note: Only acts when size is Custom.

### Hook tip drop

Customizer name: `custom_t_hook_tip_drop`

Changes no shape of the printed tool, because the hook slot's mouth already opens through the cord end.

No picture. Only acts when size is Custom. Changes no shape: the hook slot's mouth already opens through the cord end (the body ends at Y = 0), so sagging the mouth farther below that edge cuts only air; measured at 1.98, 4 and 0.

- Default: 1.98 mm
- Range: 0 to 5 mm, in steps of 0.05 mm

## Plug Wall Notch (Custom size only)

### Wall notch on or off

Customizer name: `custom_enable_plug_wall_notch`

Cuts or leaves out the notch at the plug end that straddles the outlet's cover plate.

Wall notch on or off: before and after, true to false; red marks the wall notch.

Two top views of the one-sided puller, before left and after right, the plug end at the top. Left: the defaults with hand size set to Custom, a 25 mm wide plug in teal. Right: wall notch on or off set to false. Marked in red: 1, the wall notch: the notch in the top edge. The body edge, the pocket, the seat and the wing openings stay where they were.

- Default: On
- Choices: On or off (a check box)
- Moves: wall notch

Note: Only acts when size is Custom.

### Wall notch width

Customizer name: `custom_plug_wall_notch_width`

Widens or narrows the notch at the plug end.

Wall notch width: before and after, 26.67 to 20 mm; red marks the wall notch.

Two top views of the one-sided puller, before left and after right, the plug end at the top. Left: the defaults with hand size set to Custom, a 25 mm wide plug in teal. Right: wall notch width at 20 mm. Marked in red: 1, the wall notch: the notch in the top edge. The body edge, the pocket, the seat and the wing openings stay where they were.

- Default: 26.67 mm
- Range: 5 to 40 mm, in steps of 0.01 mm
- Moves: wall notch

Note: Only acts when size is Custom.

### Wall notch depth

Customizer name: `custom_plug_wall_notch_height`

Cuts the notch deeper or shallower into the plug end.

Wall notch depth: before and after, 3.81 to 7 mm; red marks the wall notch, the wing openings and the zip-tie holes.

Two top views of the one-sided puller, before left and after right, the plug end at the top. Left: the defaults with hand size set to Custom, a 25 mm wide plug in teal. Right: wall notch depth at 7 mm. Marked in red: 1, the zip-tie holes and the wall notch: the four small holes beside the pocket; the notch in the top edge. The body edge, the pocket, the seat and the wing openings stay where they were.

- Default: 3.81 mm
- Range: 0 to 10 mm, in steps of 0.05 mm
- Moves: wall notch, wing openings, zip-tie holes

Note: Only acts when size is Custom.

### Wall notch corner rounding

Customizer name: `custom_plug_wall_notch_rounding`

Rounds or squares the notch's two inner corners.

Wall notch corner rounding: before and after, 2.54 to 0 mm; red marks the wall notch.

Two top views of the one-sided puller, before left and after right, the plug end at the top. Left: the defaults with hand size set to Custom, a 25 mm wide plug in teal. Right: wall notch corner rounding at 0 mm. Marked in red: 1, the wall notch: the notch in the top edge. The body edge, the pocket, the seat and the wing openings stay where they were.

- Default: 2.54 mm
- Range: 0 to 5 mm, in steps of 0.01 mm
- Moves: wall notch

Note: Only acts when size is Custom.

## Zip Tie Holes (Custom size only)

### Zip-tie hole diameter

Customizer name: `custom_zip_tie_hole_diameter`

Widens every zip-tie hole.

Zip-tie hole diameter: before and after, 5.08 to 7 mm; red marks the wing openings and the zip-tie holes.

Two top views of the one-sided puller, before left and after right, the plug end at the top. Left: the defaults with hand size set to Custom, a 25 mm wide plug in teal. Right: zip-tie hole diameter at 7 mm. Marked in red: 1, the zip-tie holes: the four small holes beside the pocket. 2, the wing openings: the two openings beside the pocket. The body edge, the pocket, the seat and the wall notch stay where they were.

- Default: 5.08 mm
- Range: 2 to 8 mm, in steps of 0.02 mm
- Moves: wing openings, zip-tie holes

Note: Only acts when size is Custom.

### Zip-tie row spacing

Customizer name: `custom_zip_tie_height_spacing`

Moves the second row of zip-tie holes closer to or farther from the first.

Zip-tie row spacing: before and after, 17.78 to 12 mm; red marks the wing openings and the zip-tie holes.

Two top views of the one-sided puller, before left and after right, the plug end at the top. Left: the defaults with hand size set to Custom, a 25 mm wide plug in teal. Right: zip-tie row spacing at 12 mm. Marked in red: 1, the wing openings: the two openings beside the pocket. 2, the zip-tie holes: the four small holes beside the pocket.

- Default: 17.78 mm
- Range: 5 to 30 mm, in steps of 0.02 mm
- Moves: wing openings, zip-tie holes

Note: Only acts when size is Custom.

### Zip-tie column spacing

Customizer name: `custom_zip_tie_width_spacing`

Moves no zip-tie hole, because the two columns follow the pocket wall, and only feeds the auto-fit keep-out that can trim the row spacing by a hair.

No picture. Changes no shape of its own: the zip-tie columns sit zip_edge_offset inside the pocket wall; this dial only feeds the auto-fit finger keep-out, which trimmed the row spacing by 0.05 mm at the Custom defaults.

- Default: 17.7 mm
- Range: 10 to 50 mm, in steps of 0.02 mm

### Zip-tie distance from the notch

Customizer name: `custom_zip_tie_distance_from_notch`

Moves the first row of zip-tie holes farther from the wall notch, and the second row follows.

Zip-tie distance from the notch: before and after, 5.1 to 9 mm; red marks the wing openings and the zip-tie holes.

Two top views of the one-sided puller, before left and after right, the plug end at the top. Left: the defaults with hand size set to Custom, a 25 mm wide plug in teal. Right: zip-tie distance from the notch at 9 mm. Marked in red: 1, the zip-tie holes: the four small holes beside the pocket. 2, the wing openings: the two openings beside the pocket.

- Default: 5.1 mm
- Range: 1 to 15 mm, in steps of 0.05 mm
- Moves: wing openings, zip-tie holes

Note: Only acts when size is Custom.

### Zip-tie countersink

Customizer name: `custom_zip_tie_countersink`

Flares the top of the zip-tie holes wider so the tie head sits flush.

Zip-tie countersink: before and after, 0.9 to 2.5 mm; red marks the pocket and the zip-tie holes.

Two vertical slices of the one-sided puller at x = 10.4 mm, before left and after right, the top face up. Left: the defaults with hand size set to Custom, the plug in teal in the cut. Right: zip-tie countersink at 2.5 mm. Marked in red: 1, the zip-tie holes: the four small holes beside the pocket. 2, the zip-tie holes and the pocket: the four small holes beside the pocket; the plug recess on the centerline.

- Default: 0.9 mm
- Range: 0 to 3 mm, in steps of 0.05 mm
- Moves: pocket, zip-tie holes

Note: Only acts when size is Custom.

## Velcro / Wing Strap Holes (Custom size only)

### Strap slot length

Customizer name: `custom_velcro_hole_length`

Lengthens each plain strap slot along its lean.

Strap slot length: before and after, 12 to 18 mm; red marks the classic slots.

Two top views of the one-sided puller, before left and after right, the plug end at the top. Left: the defaults with hand size set to Custom and strap opening style set to Classic slot, a 25 mm wide plug in teal. Right: strap slot length at 18 mm. Marked in red: 1, the classic slots: the two slots beside the pocket. The body edge, the pocket, the seat and the wall notch stay where they were.

- Default: 12 mm
- Range: 6 to 20 mm, in steps of 0.5 mm
- Moves: classic slots

Note: Only acts when size is Custom and velcro_style is Classic slot, or when velcro_placement is Manual.

### Strap slot width

Customizer name: `custom_velcro_hole_width`

Widens each plain strap slot.

Strap slot width: before and after, 7 to 11 mm; red marks the classic slots.

Two top views of the one-sided puller, before left and after right, the plug end at the top. Left: the defaults with hand size set to Custom and strap opening style set to Classic slot, a 25 mm wide plug in teal. Right: strap slot width at 11 mm. Marked in red: 1, the classic slots: the two slots beside the pocket. The body edge, the pocket, the seat and the wall notch stay where they were.

- Default: 7 mm
- Range: 3 to 14 mm, in steps of 0.5 mm
- Moves: classic slots

Note: Only acts when size is Custom and velcro_style is Classic slot, or when velcro_placement is Manual.

### Strap slot distance from the centerline

Customizer name: `custom_velcro_hole_x_center`

Moves the two plain strap slots closer to or farther from the centerline.

Strap slot distance from the centerline: before and after, 19.4 to 14 mm; red marks the classic slots.

Two top views of the one-sided puller, before left and after right, the plug end at the top. Left: the defaults with hand size set to Custom and strap opening style set to Classic slot, a 25 mm wide plug in teal. Right: strap slot distance from the centerline at 14 mm. Marked in red: 1, the classic slots: the two slots beside the pocket.

- Default: 19.4 mm
- Range: 5 to 35 mm, in steps of 0.05 mm
- Moves: classic slots

Note: Only acts when size is Custom and velcro_style is Classic slot, or when velcro_placement is Manual.

### Strap slot position along the body

Customizer name: `custom_velcro_hole_y_center`

Slides the two plain strap slots toward the cord end or the plug end.

Strap slot position along the body: before and after, 46 to 38 mm; red marks the classic slots.

Two top views of the one-sided puller, before left and after right, the plug end at the top. Left: the defaults with hand size set to Custom and strap opening style set to Classic slot, a 25 mm wide plug in teal. Right: strap slot position along the body at 38 mm. Marked in red: 1, the classic slots: the two slots beside the pocket.

- Default: 46 mm
- Range: 30 to 80 mm, in steps of 0.5 mm
- Moves: classic slots

Note: Only acts when size is Custom, velcro_style is Classic slot and velcro_placement is Auto.

### Strap slot lean

Customizer name: `custom_velcro_hole_rotation`

Leans the two plain strap slots more or less steeply, mirrored on the two sides.

Strap slot lean: before and after, 23.5 to 60 deg; red marks the classic slots.

Two top views of the one-sided puller, before left and after right, the plug end at the top. Left: the defaults with hand size set to Custom and strap opening style set to Classic slot, a 25 mm wide plug in teal. Right: strap slot lean at 60 deg. Marked in red: 1, the classic slots: the two slots beside the pocket.

- Default: 23.5 degrees
- Range: 0 to 180 degrees, in steps of 0.5 degrees
- Moves: classic slots

Note: Only acts when size is Custom and velcro_style is Classic slot, or when velcro_placement is Manual.

## Edge Rounding (Custom size only)

### Body side rounding

Customizer name: `custom_body_side_rounding`

Rounds the body outline's corners more or less, down to the plain octagon at 0.

Body side rounding: before and after, 15.85 to 5 mm; red marks the body edge.

Two top views of the one-sided puller, before left and after right, the plug end at the top. Left: the defaults with hand size set to Custom, a 25 mm wide plug in teal. Right: body side rounding at 5 mm. Marked in red: 1, the body edge: the outer outline. Everything else follows the outline.

- Default: 15.85 mm
- Range: 0 to 30 mm, in steps of 0.05 mm
- Moves: body edge

Note: Only acts when size is Custom.

### Top edge rounding

Customizer name: `custom_body_top_rounding`

Rounds or squares the edge where the body's top face meets its sides.

Top edge rounding: before and after, 2.54 to 0 mm; red marks the body edge.

Two vertical slices of the one-sided puller at y = 35 mm, before left and after right, the top face up. Left: the defaults with hand size set to Custom, the plug in teal in the cut. Right: top edge rounding at 0 mm. Marked in red: 1, the body edge: the outer outline. Everything else follows the outline.

- Default: 2.54 mm
- Range: 0 to 5 mm, in steps of 0.01 mm
- Moves: body edge

Note: Only acts when size is Custom.

### Bottom edge rounding

Customizer name: `custom_body_bottom_rounding`

Rounds or squares the edge where the body's bottom face meets its sides.

Bottom edge rounding: before and after, 0 to 2 mm; red marks the body edge.

Two vertical slices of the one-sided puller at y = 35 mm, before left and after right, the top face up. Left: the defaults with hand size set to Custom, the plug in teal in the cut. Right: bottom edge rounding at 2 mm. Marked in red: 1, the body edge: the outer outline. Everything else follows the outline.

- Default: 0 mm
- Range: 0 to 5 mm, in steps of 0.1 mm
- Moves: body edge

Note: Only acts when size is Custom.

### Strap slot corner rounding

Customizer name: `custom_velcro_side_rounding`

Rounds the four corners of each plain strap slot.

Strap slot corner rounding: before and after, 0 to 2.5 mm; red marks the classic slots.

Two top views of the one-sided puller, before left and after right, the plug end at the top. Left: the defaults with hand size set to Custom and strap opening style set to Classic slot, a 25 mm wide plug in teal. Right: strap slot corner rounding at 2.5 mm. Marked in red: 1, the classic slots: the two slots beside the pocket. The body edge, the pocket, the seat and the wall notch stay where they were.

- Default: 0 mm
- Range: 0 to 3 mm, in steps of 0.5 mm
- Moves: classic slots

Note: Only acts when size is Custom and velcro_style is Classic slot, or when velcro_placement is Manual.

### Strap opening edge rounding

Customizer name: `custom_velcro_top_bottom_rounding`

Flares the top and bottom edges of the strap openings so the strap does not chafe.

Strap opening edge rounding: before and after, 0 to 1.5 mm; red marks the pocket and the wing openings.

Two vertical slices of the one-sided puller at y = 46 mm, before left and after right, the top face up. Left: the defaults with hand size set to Custom, the plug in teal in the cut. Right: strap opening edge rounding at 1.5 mm. Marked in red: 1, the wing openings: the two openings beside the pocket. 2, the wing openings and the pocket: the two openings beside the pocket; the plug recess on the centerline.

- Default: 0 mm
- Range: 0 to 3 mm, in steps of 0.1 mm
- Moves: pocket, wing openings

Note: Only acts when size is Custom.

### Finger hole rim rounding

Customizer name: `custom_finger_hole_rounding`

Rounds or squares the rims of both finger holes on both faces.

Finger hole rim rounding: before and after, 2.5 to 0 mm; red marks the finger holes.

Two vertical slices of the one-sided puller at y = 19.8 mm, before left and after right, the top face up. Left: the defaults with hand size set to Custom, the plug in teal in the cut. Right: finger hole rim rounding at 0 mm. Marked in red: 1, the finger holes: the two large holes in the lower half. The body edge, the pocket, the seat and the wall notch stay where they were.

- Default: 2.5 mm
- Range: 0 to 5 mm, in steps of 0.1 mm
- Moves: finger holes

Note: Only acts when size is Custom.

### Hook crossbar corner rounding

Customizer name: `custom_t_hook_holder_side_rounding`

Rounds or squares the top corners of the hook's crossbar.

Hook crossbar corner rounding: before and after, 1.27 to 0 mm; red marks the hook.

Two top views of the one-sided puller, before left and after right, the plug end at the top. Left: the defaults with hand size set to Custom, a 25 mm wide plug in teal. Right: hook crossbar corner rounding at 0 mm. Marked in red: 1, the hook: the cord hook slot in the bottom edge. The body edge, the pocket, the seat and the wall notch stay where they were.

- Default: 1.27 mm
- Range: 0 to 3 mm, in steps of 0.01 mm
- Moves: hook

Note: Only acts when size is Custom.

### Hook slot corner rounding

Customizer name: `custom_t_hook_gap_side_rounding`

Changes no shape of the printed tool, because the J-hook cord catch draws its own corners.

No picture. Changes no shape: the J-hook cord catch is drawn without this dial; it only appears in the Cutouts Only 2D debug overlay.

- Default: 0 mm
- Range: 0 to 3 mm, in steps of 0.1 mm

### Hook edge rounding

Customizer name: `custom_t_hook_top_bottom_rounding`

Flares the top and bottom edges of the cord hook's slot and crossbar.

Hook edge rounding: before and after, 0 to 2 mm; red marks the hook.

Two vertical slices of the one-sided puller at x = 4.5 mm, before left and after right, the top face up. Left: the defaults with hand size set to Custom, the plug in teal in the cut. Right: hook edge rounding at 2 mm. Marked in red: 1, the hook: the cord hook slot in the bottom edge. The body edge, the pocket, the seat and the wall notch stay where they were.

- Default: 0 mm
- Range: 0 to 3 mm, in steps of 0.1 mm
- Moves: hook

Note: Only acts when size is Custom.

## Render, export and print

1. On the computer, press **F6** (or **Design ▸ Render**) and wait for the progress bar to finish; a render takes from a few seconds to a minute. In Forge, the preview draws on its own: wait for **Preview ready** under the picture.
2. Look for red text beside the part. If there is any, read it: it names the measurement to fix, and the part will not fit until it is gone.
3. Save the file: on the computer, **File ▸ Export ▸ Export as STL**; in Forge, **Export STL**. If you export without rendering, OpenSCAD asks you to render first: press F6 and export again. The quick preview (F5) looks complete but cannot be exported.

Load the STL into your slicer with these settings:

| Setting | Value |
| --- | ----- |
| Orientation | flat face down on the bed, the plug pocket facing up. No supports. |
| Layer height | 0.2 mm |
| Walls | 3 to 4: you pull hard on this part |
| Infill | 25 to 35 percent |
| Material | PETG. PLA, ABS and ASA work too. Never a flexible filament: the tool has to stay stiff. |

The picture shows nine one-sided pullers printed this way, in three sizes, all flat on the bed.

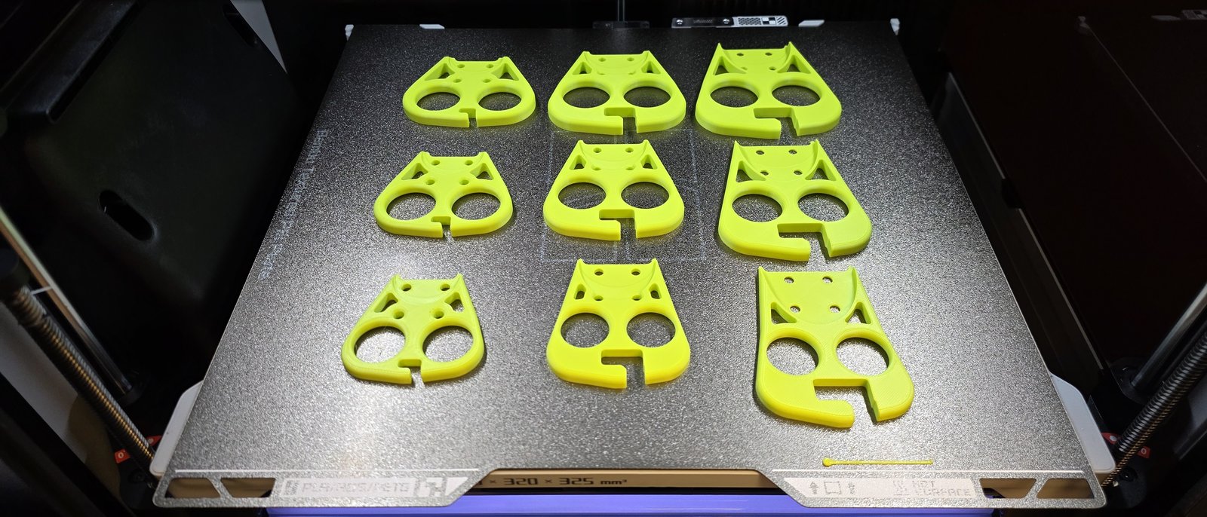
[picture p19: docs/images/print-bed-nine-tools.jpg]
Nine one-sided pullers in three sizes printed flat on the printer bed, the pocket side up, no supports.


### What to buy

Nothing to solder and almost nothing to buy: filament, zip ties, and a strap if you want one. For the one-sided puller you need two zip ties up to 4.8 mm wide (about 200 mm long), or one hook-and-loop strap 10 to 25 mm wide. The filament each tool uses, and the strap widths that fit, are in the [bill of materials](../bom.md).

## Assemble

The tool goes onto the plug while the plug is in the outlet. You need two zip ties, or a strap; the sizes are in the [bill of materials](../bom.md).

1. Seat the tool on the plugged-in plug: the plug sits in the pocket, and the notch at the plug end straddles the outlet cover.
2. Press the cord into the hook at the cord end so it cannot slip out.
3. Push the first zip tie down through one of the zip-tie holes beside the pocket.
4. Pass the tie around the plug body and up through the hole on the other side of the pocket.
5. Pull the tie tight and cut off the tail.
6. Fit the second zip tie through the other pair of holes the same way.
7. Instead of the ties, or as well: thread the strap through the two wing openings and around the plug, and close it. The picture shows a strap holding the tool on a three-prong plug.

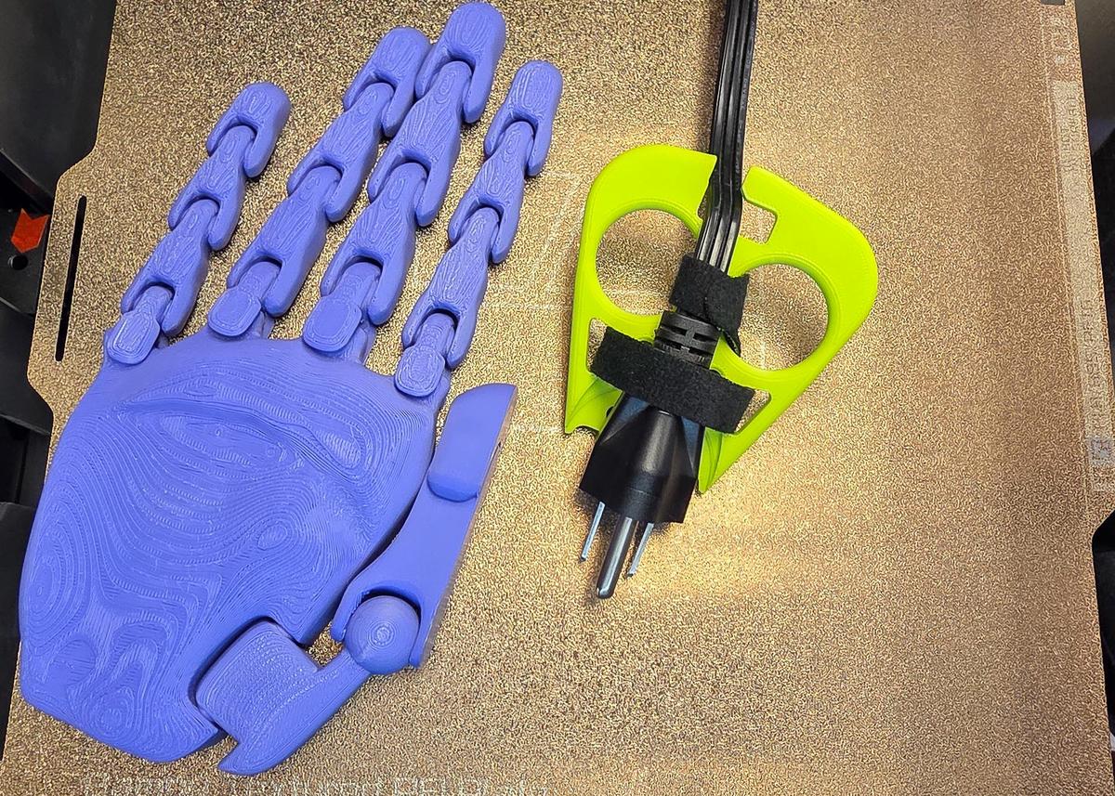
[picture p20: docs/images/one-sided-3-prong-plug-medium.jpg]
The one-sided puller at Medium size held on a black three-prong plug by a strap through its wing openings, on the printer bed beside a printed hand model for scale.
   

The tool can stay on the plug between uses. The pictures below show the finished one-sided puller strapped to a lamp plug at Small, Medium and Large, next to a printed hand for scale.

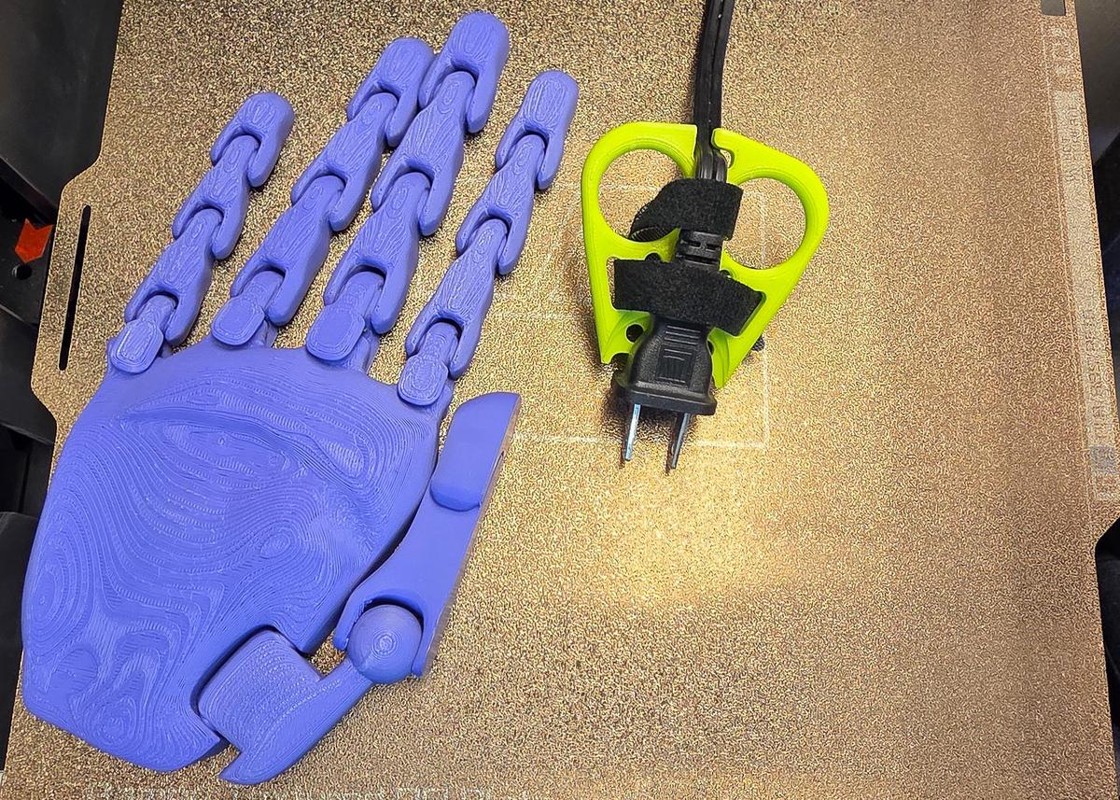
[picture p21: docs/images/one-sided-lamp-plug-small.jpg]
The one-sided puller at Small size strapped to a black two-prong lamp plug, on the printer bed beside a printed hand model for scale.


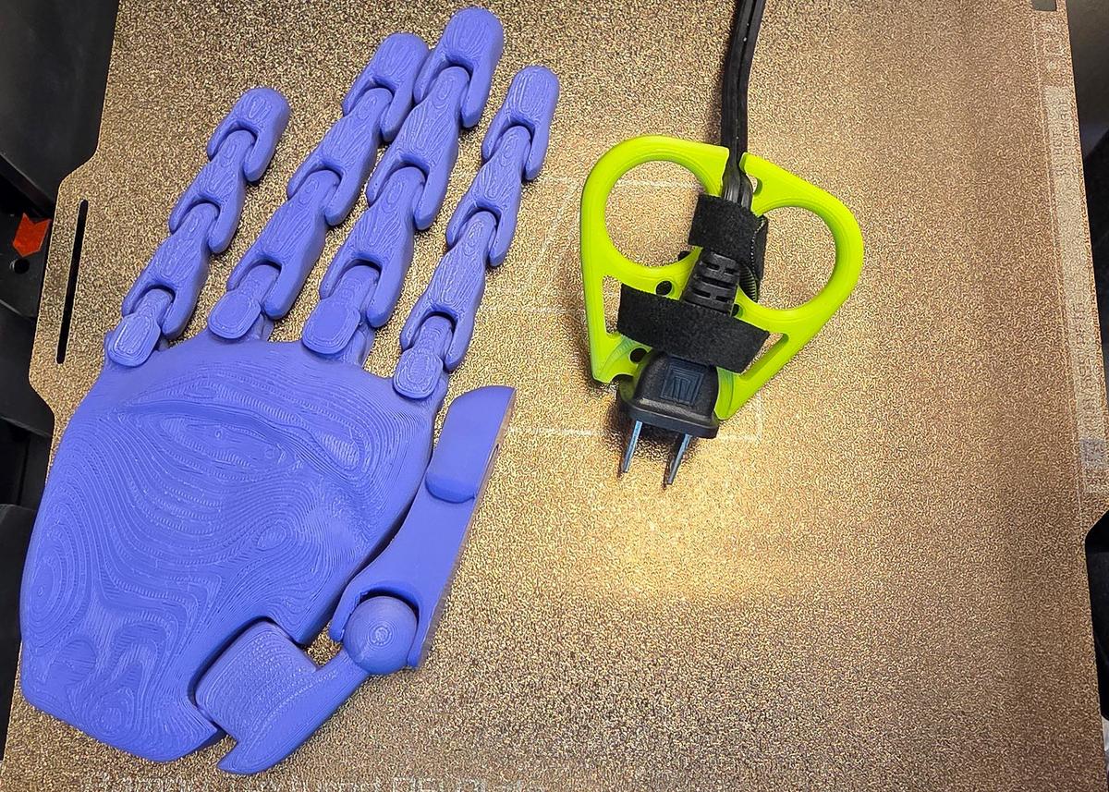
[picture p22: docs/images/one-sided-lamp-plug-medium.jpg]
The one-sided puller at Medium size strapped to a black two-prong lamp plug, beside a printed hand model for scale.


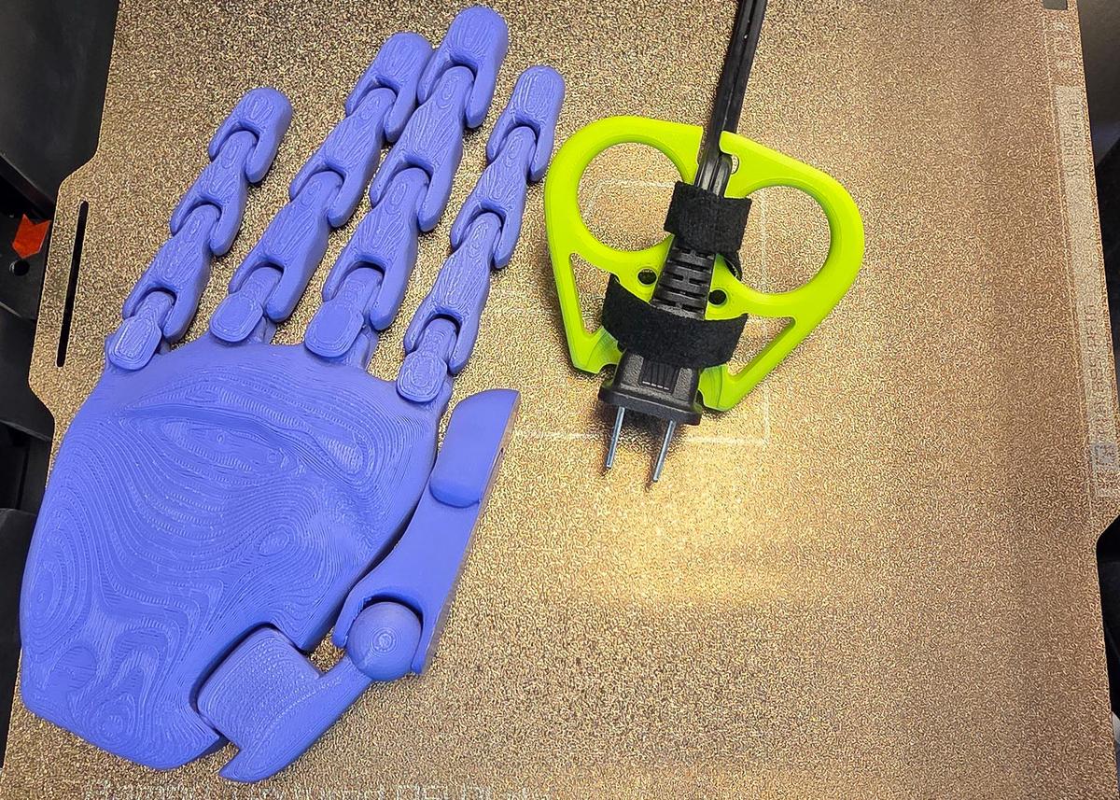
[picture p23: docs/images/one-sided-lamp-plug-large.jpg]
The one-sided puller at Large size strapped to a black two-prong lamp plug, beside a printed hand model for scale.


## Use it

The plug puller is for anyone who cannot grip a plug and pull it out of an outlet: arthritis, low grip strength, tremor, a small hand, one hand. Two finger holes take the pull, so your whole hand does the work instead of a fingertip pinch. The tool touches only the plug's sides and back, never the outlet.

1. Seat the tool on the plug while the plug is in the outlet: the plug in the pocket, the notch at the plug end over the outlet cover.
2. Press the cord into the hook at the cord end.
3. Put two fingers through the holes.
4. Pull straight back, away from the wall.

The tool can stay strapped to the plug between uses.

### Safety

- Nothing goes between the plug face and the outlet cover: the tool grips only the plug's sides and back.
- Pull straight out. Never lever the tool sideways or up and down.
- Do not use the tool on a damaged cord, a cracked plug, or a plug that is warm to the touch.
- Keep your fingers away from the prongs as the plug comes out.
- The tool has no conductive parts, but it is still plastic near electricity: if it cracks, stop using it.

### Care

- Before each use, look at the finger holes and the places the zip ties or the strap pass through for cracks. A cracked tool is replaced, not repaired.
- Replace a zip tie that has loosened.
- Wash with soap and warm water. No solvents: they attack PETG and PLA.
- Keep it out of direct sun and off heaters; the plastic softens when hot.

## If the print does not fit

Printed your tool and something is not quite right? Find your symptom below. Every fix names one measurement to change and by how much. Change it in the Customizer, render and export again, and reprint. You never need to touch anything below the four Steps.

> Nudge in small steps, 0.5 to 2 mm. Looser always beats tighter: a slightly roomy tool still works, a tight one does not.

| # | Symptom | Change this | By how much |
| --- | --- | --- | --- |
| 1 | The plug body rubs the sides of the notch, or will not slide in | Plug width at the prong end | +1 mm |
| 2 | The plug falls out of the notch or rattles side to side | Plug width at the prong end | −0.5 mm |
| 3 | The plug will not seat down into the pocket | Plug length | +2 mm |
| 4 | The plug seats, but the tool overhangs the plug by a lot | Plug length | −2 mm |
| 5 | The plug sits proud of the pocket, or the tool rocks on top of it | Plug thickness, at the end that measured fatter | +2 mm |
| 6 | The pocket walls pinch the plug's cord end, or gape at it | Plug width at the cord end | +1 mm if it pinches, −1 mm if it gapes |
| 7 | The hook will not take the cord, or the cord has to be forced in | Cord thickness | +0.5 mm |
| 8 | The cord slips out of the hook while pulling | Cord thickness | −0.5 mm |
| 9 | The tool will not sit flat against the wall; the outlet cover pushes it away | Outlet cover plate style | the next bigger style: Standard flat plate, then Rocker / Decora, then Oversized / Jumbo |
| 10 | Fingers pinch in the holes, or a knuckle drags on the rim | Hand size up one step, or Measure my hand with the finger width | +1 mm |
| 11 | Fingers swim in the holes and the pull feels sloppy | Hand size down one step, or Measure my hand with the finger width | −1 mm |
| 12 | The tool's edges dig into your palm, or it feels too wide | Hand size down one step, or Measure my hand with the hand width | −5 mm |
| 13 | The tool feels too small in the hand; fingers crowd the edges | Hand size up one step, or Measure my hand with the hand width | +5 mm |
| 14 | The tool is too wide for a cramped outlet corner | Hand size down one step: the body follows the hand size | |
| 15 | The strap keeps sliding off the plug | Attachment: Zip ties + Velcro, and use both | |
| 16 | A smooth round plug still slips out of the zip-tie hold | Thread a zip tie down one zip-tie hole, around the plug body, up the opposite hole, and cinch it | |
| 17 | The hook is on the wrong side for your hand | Step 4: Hook side, Left or Right | |
| 18 | The strap will not thread through the wing opening | Step 3: a smaller Strap width, or a narrower strap; the wing is sized to it | |

### Red warning tags

If the preview shows red text, or a red text tag printed next to your part, the file found a problem before you wasted a full print. That is on purpose: a bad file fails loudly instead of silently. Read the tag, fix that measurement, and export again.

| The tag says | What it means | What to do |
| --- | --- | --- |
| `CHECK PLUG LENGTH MEASUREMENT (MM?)`, and the same for `PLUG WIDTH`, `PLUG THICKNESS`, `CORD THICKNESS`, `FINGER WIDTH`, `HAND WIDTH` | That number is outside any plausible mm value: usually inches typed into a mm field (1.25 instead of 32) | Measure again with the mm side of the ruler and type it again |
| `FINGER TOO BIG FOR HAND WIDTH - RECHECK BOTH` | Finger holes that wide cannot fit inside a body sized for that hand width | Measure both the finger width and the hand width again; one of them is off |
| `PLUG TOO WIDE FOR THIS DESIGN (MAX 38MM)` | The plug, at the prong end, is wider than the tool's end can open | The one-sided puller tops out near 38 mm of plug width; a plug that wide needs the two-sided puller |
| `PLUG THICKER THAN 24MM - USE THE TWO-SIDED PULLER FILE` | The plug is 24 mm thick or more at one end: too thick for this tool's pocket | Open the two-sided puller and fill in its Step 1; or measure the thickness again at both ends |
| `PLUG LONGER THAN POCKET LIMIT - POCKET SHORTENED` | The plug is longer than the pocket can be inside the 120 mm body, so the pocket stops short | Check the plug length; if it is real, print and try it |
| `PLUG WIDTH TAPER TOO STEEP - RECHECK BOTH WIDTHS` | The two widths describe a taper steeper than the pocket walls can follow | Measure the plug width at the prong end and at the cord end again; one of them is probably off |
| `CORD TOO THICK FOR HOOK SLOT` | The hook slot cannot open wide enough for that cord | Measure the cord's thin side again; a cord past about 9 mm does not fit the hook |
| `FINGER HOLES HIT PLUG POCKET` | Your finger and plug numbers make the holes collide with the plug pocket | Reduce the finger width slightly, or check the plug length again |
| `FINGER HOLES TOO CLOSE - WEAK BRIDGE` | The strip of plastic between the two holes is too thin to be strong | Reduce the finger width by 1 mm |
| `FINGER HOLES OUTSIDE BODY - INCREASE HAND WIDTH` | The holes for your fingers do not fit inside a body sized for your hand width | Increase the hand width, or measure both again |
| `PLUG TOO WIDE FOR TOOL END - CHECK PLUG WIDTH` | The notch came out wider than the tool's end itself | Measure the plug width again; it is probably too large |
| `PLUG SEAT OVERHANGS BODY - RECHECK PLUG WIDTH`, `PLUG POCKET OVERHANGS BODY - RECHECK PLUG WIDTH` | The plug pocket is wider than the tool body at that spot | Measure the plug width again, or go up a hand size so the body grows |
| `WING OPENING SMALLER THAN STRAP WIDTH` | The wing opening is too narrow to pass the strap you set | Lower the strap width (Step 3), or switch the strap opening style to Classic slot |
| `WING WEB COLLAPSED - NO ROOM FOR STRAP` | Features crowded the wing until no opening was left | Go up a hand size (a bigger body), or lower the strap width |
| `ZIP TIE HOLES HIT FINGER HOLES` | A zip-tie row landed too close to a finger hole; Auto placement avoids this, Manual positions or auto-fit off can cause it | Move that zip-tie pair position, or turn Auto placement back on |
| `ZIP TIE ROWS OVERLAP EACH OTHER` | Two manual zip-tie rows landed on top of each other | Spread the zip-tie pair positions at least one hole diameter apart |
| `ZIP TIE HOLES HIT VELCRO SLOTS` | A zip-tie row broke into a classic strap slot | Move the zip-tie pair or the strap slot position apart |
| `SEAT HAS NO RECESS - PLUG WONT NEST`, `POCKET HAS NO RECESS - PLUG WONT NEST` | An internal geometry check; with measured numbers it should not happen | Measure every number again, following Measure your plug and your hand; if it persists, open an issue with your numbers |
| `SEAT FLOOR TOO THIN TO PRINT`, `POCKET FLOOR TOO THIN TO PRINT` | The same internal check, on the pocket floors | As above |
| `ZIP TIE GRID BELOW CORD END`, `ZIP TIE GRID OUTSIDE BODY`, anything else | The same internal check, on the zip-tie grid | As above |
| `FINGER HOLES OUTSIDE BODY`, `POCKET SEAT WIDER THAN TOP EDGE`, `POCKET WIDER THAN BODY`, `WALL NOTCH WIDER THAN TOP EDGE` | Custom size only: the Custom-mode wording of the checks above | Adjust that feature's Custom dials, or turn Auto-fit back on |

### Notes that show in the preview only

These never reach the exported file.

| The note says | What it means | What to do |
| --- | --- | --- |
| A green `Medium: …` or `MEASURED: …` tag | Not a warning: it confirms that your size and numbers were applied | Nothing |
| Orange `CUSTOM SLIDERS IGNORED - SET SIZE = CUSTOM` | A Custom dial was moved while a measured size is active; the console names each one | Set Step 2's hand size to Custom if you meant it, or leave the dial alone |
| Orange `AUTO-FIT ADJUSTED <n> VALUES - SEE CONSOLE` | Custom size with Auto-fit on: that many dials were clamped to keep the part printable | Read the console's `(clamped from …)` lines |

### Printing problems

| Symptom | Cause | Fix |
| --- | ----- | --- |
| The slicer complains about floating or disconnected parts | You exported with a red warning tag showing; the tag is a separate object | Fix the named measurement first |
| Layers split at the pocket floor or around a hole | Under-extrusion, or too few walls | 3 to 4 walls and 25 percent infill or more |
| The tool snapped while pulling | A brittle material, or walls too thin | Reprint in PETG with 4 walls |

## Advanced settings

Everything below Step 4 in the Customizer is optional. The **Advanced** sections hold placement dials that work with your measured sizes and apply in every hand size. The sections marked **(Custom size only)** are for experts: they do nothing until Step 2's hand size is Custom, and then they replace the measurements entirely. Every one of these dials is described, with a picture, earlier in this guide.

### The plug side rail

One idea powers the one-sided puller's advanced dials: a line that runs down the plug's side, starting at the pocket edge on the plug face and sloping by the plug's taper. The taper comes from the two widths in Step 1 over the plug length (in Custom size, the pocket side taper dial sets it directly): a plug that is wider at the cord end gives a negative angle, and the pocket walls widen toward the cord. The pocket walls, the zip-tie holes and the manual strap slots all hang off this line, so their positions are measured in mm along the plug's side, from the plug face toward the cord, and the taper moves them together.
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

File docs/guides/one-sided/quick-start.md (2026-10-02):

# Quick start, one-sided puller

The shortest path from a stuck plug to a printed one-sided puller that fits it and your hand: get the file, measure, fill in the four Customizer steps, print, assemble, use.

Model version 0.14.0. [The printable quick start](../../Plug_Puller_One_Sided_Quick_Start.pdf) has the same text, with the measuring form and the paper stencil sheets at true size as its last pages. The other document for this tool is [the full guide](full-guide.md). Each step lists its dials by their plain names, with the name the Customizer shows beside each.

## Which tool this is

This guide is for the one-sided puller, src/Plug_Puller_Parametric.scad: the tool for a wall plug up to 24 mm thick, a pocket around the plug's back and sides with two finger holes below it, pulled with one hand. Measure your plug's thickness first. Thicker than 24 mm, or a plug you want held from both sides such as a USB-C tip or a round extension-cord plug, is the two-sided puller's job, and that tool has its own guide.

The Customizer's four steps are your plug, your size, the attachment and the hook's side. This quick start covers getting the file, measuring your plug and your hand or matching a card, each step's dials in a table, then printing, assembly and use.

If red text appears beside the part in the preview, read it: it names the measurement to fix, and the part will not fit until it is gone.

In every picture: black = the tool; teal = your plug; red dashed = the edges this dial moved; the numbers match the key beside the picture.

The one-sided puller, the four Customizer steps on a US vacuum plug, five stages left to right.

Five stages of the one-sided puller, left to right, the top row first, the plug end at the top; arrows numbered 1 to 4 show the steps, and red dashes mark the edges each step moved. Start, the defaults: the tool as the file opens, with a 25 mm wide plug in teal. Step 1 - Your Plug: plug length, plug width at both ends, plug thickness at both ends, cord thickness, outlet cover plate style; red on the body edge, finger holes, seat, wall notch, wing openings and zip-tie holes. Step 2 - Size: hand size, finger width, hand width; red on the body edge, finger holes, pocket, wall notch, wing openings and zip-tie holes. Step 3 - Attachment: attachment; the wing openings removed, drawn in red from the old outline. Step 4 - Cord Hook: hook side; red on the hook.

- Step 1: type your plug's numbers
- Step 2: pick your hand size
- Step 3: pick how it attaches
- Step 4: pick the hook's side

## Get the file

The one-sided puller is the file `src/Plug_Puller_Parametric.scad`. There are two ways to open it and fill in its form: in your web browser with nothing to install, or in the free OpenSCAD program on your computer. Both show the same form, called the Customizer.

### In your browser

The OpenSCAD Assistive Forge is a version of OpenSCAD that runs in your browser, on a computer or a phone, built for keyboard and screen reader use. Nothing is uploaded: your numbers stay on your device.

1. Open [the one-sided puller in the Assistive Forge](https://openscad-assistive-forge.pages.dev/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). On a first visit Forge asks which interface you want: choose **Assistive Forge**, then **Download & Continue**, and it downloads its engine once.
2. Forge offers to keep a copy of the project in your browser. Choose **Save My Copy**: the tool is then listed on Forge's main page whenever you come back, no link needed.
3. The form shows the four steps' dials first. The rest sit behind one button, **Show all parameters**.

If the link cannot load, Forge says why and offers **Try again**. You can also download the whole tool as one file, [`dist/Plug_Puller_SingleFile.scad`](../../../dist/Plug_Puller_SingleFile.scad), and open it from Forge's main page, under Open or start a project.

### On your computer

OpenSCAD is the free program that turns your numbers into a printable file. You use one panel of it and never touch the code.

1. Download OpenSCAD from <https://openscad.org/downloads.html>: the **Development Snapshot** for your system. This project is tested with the snapshot of 2026-01-03; any recent snapshot works. The regular release works too, only slower.
2. Get the project: on its GitHub page press the green **Code** button, then **Download ZIP**, and unzip it anywhere. Or download only [`dist/Plug_Puller_SingleFile.scad`](../../../dist/Plug_Puller_SingleFile.scad), the whole tool in one file.
3. Open `src/Plug_Puller_Parametric.scad` (or the single file) in OpenSCAD: double-click it, or use **File ▸ Open**. A wall of code appears in an editor pane. Ignore it; you will not touch it.
4. Show the Customizer, the form you type into: in the **View** menu, make sure **Hide Customizer** is unchecked. In older versions it is **Window ▸ Customizer**.

The form's sections read top to bottom in the order you decide things: **Step 1 - Your Plug**, **Step 2 - Size**, **Step 3 - Attachment**, then **Step 4 - Cord Hook**. Everything below Step 4 is optional.

## Measure your plug and your hand

Everything here is in mm: a US plug is about 25 mm wide, so a 1 on your paper means you measured in inches. You need a caliper or a ruler with mm marks, the plug in its outlet, and your own hand only if you pick Measure my hand. Print the measuring form at 100 % and fill it in as you go: the sections below are the form's rows, in the same order, and the card names (R1, C1, F1 / F2) are the cards of the printed measuring stencil, described under Match a card instead of measuring.

### Plug length

Customizer name: `measure_plug_length`. Row 2 of the measuring form.

With the plug in the outlet, ruler from the wall plate face to the plug's back face. On a laptop or charger plug, measure from the device's edge.

Typical: 20 to 50 mm. Example: 38 mm.

With the stencil: card R1.

### Plug width at the prong end

Customizer name: `measure_plug_width_prong_end`. Row 3 of the measuring form.

Caliper straight across the plastic body just behind the prongs, the wide way, parallel to the wall. Measure the body, not the metal prongs; if the head flares, take the widest part of that first stretch.

Typical: 20 to 38 mm. Example: 34 mm.

With the stencil: card R1.

### Plug width at the cord end

Customizer name: `measure_plug_width_cord_end`. Row 4 of the measuring form.

The same wide direction, but where the cord leaves the plug body. Skip any soft rubber strain relief and measure the last part of the hard body you would grip.

Typical: 10 to 35 mm. Example: 13 mm.

With the stencil: card R1.

### Plug thickness at the prong end

Customizer name: `measure_plug_thickness_prong_end`. Row 5 of the measuring form.

Caliper across the plug body's thin direction, usually top to bottom on a flat plug, just behind the prongs. A plug 24 mm thick or more needs the two-sided puller, so measure carefully.

Typical: 12 to 30 mm. Example: 16 mm.

With the stencil: card R1.

### Plug thickness at the cord end

Customizer name: `measure_plug_thickness_cord_end`. Row 6 of the measuring form.

The same thin direction, where the cord leaves the plug body, skipping the soft strain relief. On a round extension-cord plug this can be as fat as the prong end.

Typical: 8 to 30 mm. Example: 9 mm.

With the stencil: card R1.

### Cord thickness

Customizer name: `measure_cord_thickness`. Row 7 of the measuring form.

Caliper across the cord just behind the plug, on its thin side: flat cord the narrow way, round cord the diameter. With the stencil, the smallest C1 slot that slips over the cord is this number.

Typical: 3 to 7 mm. Example: 5 mm.

With the stencil: card C1.

### Outlet cover plate style

Customizer name: `measure_wall_plate_style`. Row 8 of the measuring form.

Look at the outlet cover plate: two small oval openings is Standard flat plate; one big rectangle per outlet is Rocker / Decora; a bigger, thicker plate is Oversized / Jumbo; no plate or a flush outlet is No plate / flush.

The choices: Standard flat plate, Rocker / Decora, Oversized / Jumbo, No plate / flush.

### Finger width

Customizer name: `measure_finger_width`. Row 11 of the measuring form.

Caliper across the widest knuckle of your middle finger, the finger that goes into the pull hole. With the stencil, find the smallest F1 or F2 hole your finger passes through comfortably and subtract 5 from its number.

Typical: 16 to 24 mm. Example: 22 mm.

With the stencil: card F1 / F2.

No caliper? Take a ring that fits that finger snugly, measure the ring's inner diameter in mm and add 1.5 mm.

### Hand width

Customizer name: `measure_hand_width`. Row 12 of the measuring form.

Caliper or ruler straight across the four knuckles of your flat hand, fingers together, no thumb. Measure at the widest point.

Typical: 70 to 100 mm. Example: 88 mm.

With the stencil: card R1.

### Strap width

Customizer name: `strap_width`. Row 15 of the measuring form.

Read the width on the strap's packaging. ONE-WRAP comes in 10, 13, 16, 20 and 25 mm.

Typical: 10 to 25 mm. Example: 15 mm.

Sanity check: each plug width is a two-digit number, roughly 12 to 45, and the prong-end width is usually the bigger one; the finger width is roughly 14 to 32. A number like 1.3 is inches: measure again with the mm side.

When you measure for someone else, a relative or a client, measure their hand for the finger and hand rows and their outlet and plug for the plug rows. Doubtful between two values? Round up: a slightly roomy fit works, a tight one does not.
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

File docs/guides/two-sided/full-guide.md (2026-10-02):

# Full guide, two-sided puller

Everything about the two-sided puller: getting the file, measuring, every dial with a picture, printing, assembly, use and care, what to do when a print does not fit, every warning, and how the advanced dials work.

Model version 0.14.0. [The printable full guide](../../Plug_Puller_Two_Sided_Full_Guide.pdf) has the same text, with the measuring form and the paper stencil sheets at true size as its last pages. The other document for this tool is [the quick start](quick-start.md). Each dial is headed by its plain name, with the name the Customizer shows on the line under it.

## Which tool this is

This guide is for the two-sided puller, src/Plug_Puller_Two_Sided.scad: two serrated plates that zip-tie around the plug and close across it, for a plug 24 mm thick or more and for a plug held from both sides, a USB-C tip or a round extension-cord plug. A thinner wall plug is the one-sided puller's job, and that tool has its own guide.
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

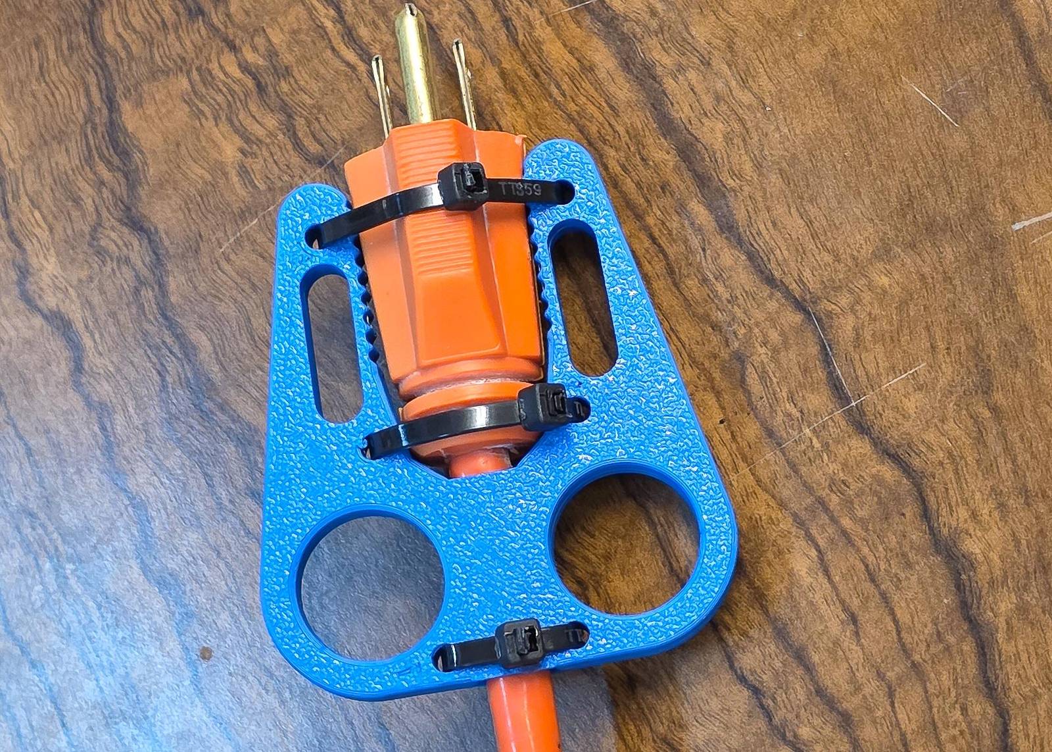
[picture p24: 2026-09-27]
docs/images/two-sided-assembly-step-6.jpg

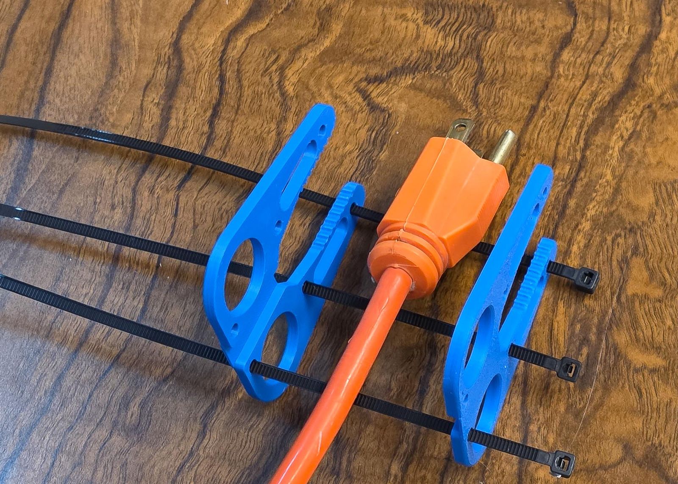
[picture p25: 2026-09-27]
docs/images/two-sided-assembly-step-3.jpg

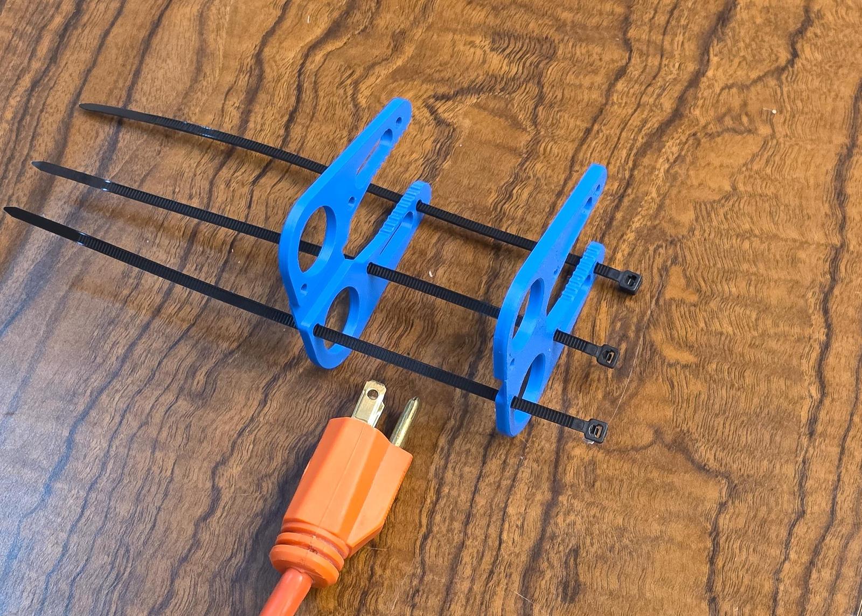
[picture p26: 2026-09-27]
docs/images/two-sided-assembly-step-2.jpg

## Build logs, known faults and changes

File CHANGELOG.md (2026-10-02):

# Changelog

All notable changes to this project will be documented in this file.

The format is based on [Keep a Changelog](https://keepachangelog.com/en/1.1.0/),
and this project adheres to [Semantic Versioning](https://semver.org/spec/v2.0.0.html).

Versions below 1.0.0 are public preview releases: the model is complete
and print-tested, but small refinements are expected before the **v1.0
public milestone**.

## [Unreleased]

Nothing yet.

## [0.14.0] - 2026-10-01

### Changed

- **The STL library and the test fixtures are binary STLs**, the same shapes
  in about a fifth of the bytes: the 46 files shrink from 500 MB to 87 MB,
  each proven the same shape as its text version. Binary STL's 32-bit
  coordinates collapse a few of OpenSCAD's shortest edges into triangles
  with no area, 36 of them in three files, so those are dropped and every
  file stays watertight; no surface moves. `scripts/build_release_stls.py`
  and `scripts/regenerate_fixtures.py` now leave a file alone when its shape
  did not change (`--force` replaces every file), so a rebuild that moved
  nothing adds nothing to the repository's history.
- **The golden-fixture comparison is tighter:** volume and surface area
  within 0.05 % and the overall size within 0.01 mm, instead of 1 %, 0.5 %
  and 0.1 mm. Two renders of a fixture differ by at most 0.000006 %, and a
  drift like the 0.77 % one a fixture once showed while its plug numbers
  were ignored now fails.
- **Two documents per tool replace the guide packets and the cross-tool
  guides.** Each tool now has a **quick start** (get the file, measure your
  plug and your hand or match a stencil card, the four Customizer steps
  as tables of their dials, render and print, assemble, use, safety) and a
  **full guide** (the same, plus the browser notes, the outline sheets,
  every optional dial, what to buy, care, the fit table, every red warning
  tag, printing problems, how the advanced dials work, saved settings and
  the command line), each as a page under `docs/guides/<tool>/` and as a
  printable PDF (`docs/Plug_Puller_<Tool>_Quick_Start.pdf`,
  `docs/Plug_Puller_<Tool>_Full_Guide.pdf`) whose last pages are the
  measuring form and the 1:1 paper stencil sheets. The hand-written text
  lives once, one topic per file under `docs/guides/source/`, and
  `scripts/build_dial_reference.py` assembles all four documents from it
  (`scripts/guide_text.py` loads and converts the sources). The README, the
  OKH manifest and the MakerWorld quick start point at the new documents.
- **The browser path is the OpenSCAD Assistive Forge.** The README, the
  MakerWorld quick start and each tool's documents now open the tool in
  the [Assistive Forge](https://openscad-assistive-forge.pages.dev/), the
  project's own browser OpenSCAD built for keyboard and screen reader use,
  from one link that offers to keep a copy in the browser and shows the
  four steps' dials first (the manifests, single files and presets live on
  the Forge's `example-manifest` branch under `plug-puller/`); the OpenSCAD
  Playground links are gone.
- **Dial texts checked against the model.** The hook tip drop card says it
  changes no shape, as its own note always did. The two-sided plug preset
  card speaks of any of its four reference plugs and says each sets the plug
  sides. The strap slot placement help says Manual placement gives classic
  slots even with the Wing style, and the classic-slot notes now include
  that case. Three help texts lose a British spelling, an old "T-shaped"
  name for the J-shaped cord hook, and internal version names.
- **Every major section of the four documents starts at the top of a new
  page**, a heading is never left at the foot of a page without its text,
  table or list, a short list or table is never split across pages, and
  photos that follow each other stand in one row (assembly steps with a
  photo each in three columns). The quick starts list each step's dials in
  a table (the full guides keep the picture cards), the measuring section
  is a table in the print, and the printed form section names the sheet's
  page and leaves the sheet's text description to the web page. The quick
  starts are 13 (two-sided) and 15 (one-sided) pages, four to five of them
  the cover, the contents, the form and the stencil sheets.
- **The measuring pictures say what their red line measures.** Each of the
  13 before-and-after pictures with a red dimension line now has one
  sentence in its description saying what the line marks and that its
  number is the one you type. Where the part is drawn at another size, the
  sentence gives that size and why: a hook slot or cord channel wider than
  the cord, a finger hole wider than the finger, a body narrower than the
  hand. These 13 descriptions may run to 110 words instead of 90, so none loses
  the phrases saying where each marked part sits.
- **The storyboard descriptions follow the picture.** Their lines read
  Start, then Step 1 to Step 4, as the picture numbers its arrows, instead
  of 1 to 5, and the one-sided storyboard names all seven Step 1 dials
  instead of three and "4 more".
- **The four documents read like a printed guide.** The quick starts' and
  full guides' PDFs print on US Letter pages (the measuring form keeps its
  210 × 279 mm sheet at 1:1, centered), with a cover, a contents page with
  page numbers, and the document's name, the tool's name and "Page N of M"
  on every page. Every dial card is headed by its plain title, with the
  name the Customizer shows on the line under it, the sentence of what it
  does above its picture, and its numbers in plain words (a check box reads
  On or Off); a dial that changes no shape says so in one line instead of
  an empty picture box. The pages under `docs/guides/one-sided/` and
  `docs/guides/two-sided/` follow the same layout.
- **Each edge in the dial pictures is drawn in one style only.** In every
  before-and-after picture and both storyboards, an edge that moved is drawn
  only as thick red dashes (long dashes, short gaps, thicker than the black
  outline); the black line under it is left out, and a stretch two red lines
  shared is drawn once. Unmoved edges stay solid or dashed black. The picture
  key now reads "red dashed = the edges this dial moved", and the key box in
  both guides shows the same dashes.
- **The MakerWorld listing is cleared to publish.** The maintainer chose to
  publish on MakerWorld with CC BY-NC-SA 4.0 as the listing license; the
  repository stays under PolyForm Noncommercial 1.0.0. The listing and the
  README record the decision, and the upload waits only on the listing's
  pre-publish checklist.

### Removed

- The Cline rules file (`.clinerules/project-facts.md`) and the VS Code
  workspace file: local development files, not part of the project.
  `.gitignore` now keeps every AI assistant's rules, memory and skills files
  and `*.code-workspace` out of the repository. Comments and docstrings that
  cited the maintainer's private planning notes by ID now say the same in
  plain words.
- The guide packets `docs/Plug_Puller_One_Sided_Guide.pdf` and
  `..._Two_Sided_Guide.pdf` with their `dial-guide.md`, `measuring-guide.md`
  and `measuring-form.md` pages (folded into the quick starts and full
  guides); the cross-tool guides `maker-guide.md`, `user-guide.md`,
  `quick-start-beginner.md`, `web-customizer.md`, `fit-troubleshooting.md`,
  `power-user-guide.md`, `print-preview-outlines.md` and the
  `measuring-guide.md` router (their text lives in the new documents); the
  starter guide (`starter-guide.md`, `Plug_Puller_Starter_Guide.pdf`,
  `scripts/build_starter_guide_pdf.py`, `tests/test_starter_guide_sync.py`),
  superseded by the quick starts; and the original measuring template
  (`docs/guides/measuring-template.svg`, `docs/Plug_Puller_Measuring_Template.pdf`),
  superseded by the stencil sheets and the measuring forms.

### Fixed

- **`scripts/scad-check.ps1` checks a setting whose value has spaces**, such
  as a plug preset name, from Windows PowerShell and from Git Bash, with or
  without its quotes; before, Windows PowerShell stripped the quotes and
  OpenSCAD stopped at a syntax error. A text value that is not one of the
  setting's dropdown choices now fails the check instead of quietly checking
  the default shape. The fix is logged in `docs/fixes.md`.
- **Both tools preview in seconds in a web browser.** The rounded edges
  (the one-sided puller's top edge, `body_top_rounding`, and its optional
  bottom edge, `body_bottom_rounding`; the two-sided plate's outer edge,
  `plate_edge_rounding`) were a `minkowski()` with a sphere. The
  WebAssembly build of OpenSCAD that browsers run, the one in the
  Assistive Forge, cannot compute that its fast way: its CGAL hull fails
  and it falls back to a much slower method. Opened from its Assistive
  Forge link, the one-sided puller took 22 s per preview and the
  two-sided 65 s, against 0.4 s and 1.3 s in desktop OpenSCAD. Each
  rounded edge is now a stack of 0.1 mm layers, each the rolling ball's
  cross-section at the layer's top, so every step sits on or just inside
  the old smooth surface: at most 0.09 mm inside it, and 0.1 to 0.3 % less
  volume. The steps are half a typical 0.2 mm print layer. Uploaded to the
  Assistive Forge, the one-sided file previews in 1.5 s and the two-sided
  in 2.8 s. The rounding dials keep their ranges and defaults, now checked
  with `assert()`, as is Render quality. The golden test fixtures and the
  `stl/Plug-Puller/` library are regenerated; the layers add facets, so
  the library grows from 229 MB to 286 MB.
- **The two-sided red warning tags table lists only tags you can get.** The
  `STEP 3 DISABLED ZIP HOLES - NOTHING SECURES THE TWO PLATES TOGETHER` row
  is gone from the full guide, because every Step 3 choice keeps the zip
  ties; the check stays in the model as a guard, with a comment saying why.
- **The MakerWorld listing** says that on a short plug, such as a USB-C tip,
  the strap slot is left out and the zip ties still hold the plates, since
  MakerWorld does not show the preview note that says so. Its gallery items
  4 and 5 name their photos, with alt text that describes them.
- **No pointers to deleted guides.** The one-sided plug preset help text
  and the file's opening comments send readers to the quick start and the
  full guide instead of the deleted measuring and power-user guides. The
  measuring stencil's comments name the guides' card table and the paper
  stencil sheet. A red tag row in the one-sided full guide says to measure
  again by Measure your plug and your hand instead of a deleted guide. The
  README's first red tag row links both tools' red warning tags tables,
  its preview note no longer names a version, and it drops a credit that
  linked to a private repository. The MakerWorld listing names every
  preset of both tools and no longer promises measuring photos. The
  scripts index lists `scad-check.ps1`.
- **The outline sheets PDF has a title and bookmarks.** It was titled
  `outline_sheets.html`, the name of a temporary file, and had no
  bookmarks. It is now titled "1:1 outline sheets, one-sided and two-sided
  pullers", with a bookmark for each plug and each hand size, made from
  headings a screen reader also finds. The printed pages are unchanged.
  `scripts/build_outline_sheets_pdf.py` checks the title and a bookmark on
  every page, and prints with a scratch browser profile, as the guide
  builder does, so a running Edge cannot stall it.
- **The guides name the fourth step.** All four documents read "then
  {step4}" in their Get the file section, because the pattern that finds
  placeholders in the guide sources skipped a name with a digit; they now
  read "then Step 4 - Cord Hook" or "then Step 4 - Print Layout". A test
  fails if any placeholder is left unfilled. The fix is logged in
  `docs/fixes.md`.
- **The two-sided preview plug ends at the arm tips.** The see-through plug
  in the two-sided preview reached 2 mm past the arm tips, and every
  two-sided dial picture copied it, although the model places the plug's
  face at the tips. It now spans exactly the plug's length, in the preview
  and in the pictures. The printed plates do not change.
- **The dial pictures name every hole and slot whose outline moved.** A
  moved part whose change merged into another part's marked area went
  unnamed: the plug width at the cord end and pocket side taper pictures
  drew the zip-tie holes moving by up to 5 mm, while their key and
  description named only the pocket and the wing openings. The generator
  now compares each kind of hole and slot before and after the dial moves,
  and names it on every marked area that encloses its change. Ten pictures
  now name a part they left out; nine descriptions drop the sentence on
  what the dial does or some part locations to stay within their word
  limits, in the usual order. The one-sided storyboard keeps every name by
  giving each list of parts a single "the". All 118 pictures are redrawn
  from today's model; most one-sided ones still showed the outlines from
  before the layered edge rounding, which move by hundredths of a
  millimeter.
- **A big finger keeps its full finger hole.** The auto-fit trims a finger
  hole wider than 40 % of the one-sided body's length, and with a short
  plug the fitted body was often too short: a 26 mm finger on an 85 mm
  hand with the default plug got a 27.9 mm hole instead of 31.4 mm, and
  plain Large got 27.06 mm instead of 28.4 mm, with only a console line to
  say so. The fitting step now makes the body just long enough for the
  full hole. A hand too narrow for its hole keeps its red tags, FINGER TOO
  BIG FOR HAND WIDTH and FINGER HOLES OUTSIDE BODY; a band of hands 1 to
  3 mm too narrow at the holes' height, such as a 25 mm finger on an
  80 mm hand, now sees FINGER HOLES OUTSIDE BODY instead of a silently
  smaller hole. The shipped STLs, the presets and the outline sheets do
  not change; the `large` golden fixture is regenerated, now 71.05 mm long
  instead of 67.65 mm, and the hand size and finger width pictures are
  redrawn.
- **No pointers to files a reader cannot open.** Comments in the models
  and tests, the engineering reference and one fixture description named
  development scripts and CAD files that were never public; they now say
  the work was done during development. The scripts index no longer links
  two private repositories, and a test comment no longer names a deleted
  guide.
- **No outline sheet label reads negative.** The label between the top two
  zip-tie holes on a one-sided sheet printed a signed difference, so the
  lamp plug's Medium and Small sheets read "-20.5" and "-17.71"; it now
  prints the distance, as the label beside it already did. All 21 sheets
  and their PDF are regenerated, which also brings their outlines up to
  date with the layered edge rounding; the measured labels move by at most
  0.08 mm. A test fails if any label starts with a minus sign. The fix is
  logged in `docs/fixes.md`.

## [0.13.0] - 2026-09-27

### Added

- **Plug presets from measured plugs.** The one-sided file gains
  `Wide 2-prong appliance plug - NEMA 1-15`; the two-sided file gains
  `USB-C laptop tip` (Rounded sides), `Flat 2-prong lamp plug - NEMA 1-15`
  and `Standard 3-prong plug - NEMA 5-15` (Flat sides). Each has a saved
  set under `presets/`.
- **The P4 stencil card** (`P4_Wide-2-Prong-Appliance-Gauge`, Visual and
  Tactile with its braille flap), a second paper stencil page
  (`docs/guides/stencil-sheet-2.svg`) in the Starter Guide PDF, and the
  card in the measuring guide's legend.
- **The library and the sheets grow with the presets:** 21 plug tools
  (five presets, from every file that offers each, at three sizes) and 18
  stencil cards under `stl/`; 21 outline sheets and a 22-page
  `docs/Plug_Puller_Outline_Sheets.pdf`.
- **`dial_catalog.json`**: one row per Customizer dial of both files (118),
  with a plain title, one sentence on what it changes and how to draw it;
  `tests/test_dial_catalog.py` keeps it in step with the mappings.
- **A guide packet per tool** (`docs/Plug_Puller_One_Sided_Guide.pdf`,
  `docs/Plug_Puller_Two_Sided_Guide.pdf` and their Markdown twins under
  `docs/guides/one-sided/` and `docs/guides/two-sided/`), generated from
  `dial_catalog.json` by `scripts/build_dial_reference.py --tool <t>`:
  the opener with the storyboard, the quick start (the four steps' dials),
  the full dial guide (every dial of the file as a card with its
  before-and-after picture, its sentence, the default, range, step and
  unit, its caution note, the features it moves and the warning tags it
  can trip), the measuring guide and the blank measuring form; the PDF
  has bookmarks, a linked contents page and the picture key on every
  card page.
- **A before-and-after picture for every dial** under `docs/dials/` (118
  SVGs, an index and a README), drawn by `scripts/generate_dial_diagrams.py`
  from the catalog: the tool at the dial's default on the left with the
  plug in teal, an arrow with the two values, and the tool after the dial
  moved on the right, drawn once in black with the edges that moved in
  red dots, numbered dots and a key naming the parts; the measuring dials
  carry a red dimension line with the dial's value (`diagram.dimension`
  in the catalog). Every picture has an alt text and a long description
  written by the rules in `docs/guides/describing-pictures.md`.
- **Two storyboards** (`dial_storyboards.json`,
  `docs/dials/<tool>/storyboard.svg`, `docs/dials/storyboards_index.json`):
  the four Customizer steps applied one after another to a US vacuum plug
  and to a USB-C laptop plug.
- **The measuring forms** (`docs/guides/<tool>/measuring-form.svg` and
  `.md`, drawn by `scripts/generate_measuring_form.py`): one row per Step
  dial in Customizer order with a blank or tick boxes, and a numbered
  leader from every measured row to a schematic plug; the catalog's
  `measure` rows (how to take each number, the typical range, the
  example, the stencil card, the form anchor) feed the form and the
  measuring guide. New tests: `test_measuring_form.py`,
  `test_guide_packets.py`, and the catalog, diagram and description rules.
- **The maker's manual:** `docs/guides/maker-guide.md` (choose the file,
  measure or match, customize, print, assemble), `docs/guides/user-guide.md`
  (use, safety, care), `docs/guides/bom.md` (zip ties, the strap, filament
  per tool) and `docs/guides/design-rationale.md` (why each default is what
  it is), in the Makers Making Change OpenAT shape.
- **Photos:** fifteen July 2026 photos under `docs/images/` (the one-sided
  puller on lamp and 3-prong plugs at three sizes, the two-sided assembly
  in six steps, the print bed), resized under 400 KB with no camera
  metadata, each with alt text; `scripts/render_doc_images.py` renders the
  three preview pictures, including the red warning tag.
- **`okh.yml`**, an Open Know-How manifest at the repository root.
- **The docs gate:** `scripts/check_docs.py` and `tests/test_docs_gate.py`
  hold `README.md` and `docs/**/*.md` to the documentation standard's
  mechanical rules (one H1, no skipped level, alt text on every image, no
  banned or retired word, table cells of at most 22 words, every relative
  link resolving, no compliance claim).

### Changed

- **`README.md`** reordered to the OpenAT template: Overview, How to obtain
  the device, Build instructions, How to use it, How to improve this
  device, Files, License, Attribution; the new guides are its first links;
  its documentation index and layout list the two packets and their twins.
- **The diagram README** (`docs/dials/README.md`) shows the pair pictures
  with their alt text and long description and the storyboards;
  **the measuring guide** (`docs/guides/measuring-guide.md`) is a
  one-screen router to each tool's measuring guide and form;
  `okh.yml`'s making-instructions list the two packets.
- **Six images renamed** for the two-tool vocabulary (`clamshell-*` to
  `two-sided-*`, `flat-tool-medium-render.png` to
  `one-sided-medium-render.png`); every link updated.
- **Seven Custom help texts** (one-sided file) now say what the dial
  really does: `strap_width` is only compared against the strap (the W-14
  tag) and does not size the wing opening; `custom_t_hook_gap_offset`,
  `custom_t_hook_gap_side_rounding`, `custom_pocket_dome_drop` and
  `custom_t_hook_tip_drop` change no shape of the printed tool;
  `custom_zip_tie_width_spacing` moves no hole and only feeds the auto-fit
  keep-out; `custom_t_hook_leg_offset` moves nothing on the hook and only
  pushes the finger holes through the auto-fit clamp. No geometry changed.
- **Wording:** the green preview tag is written as the file prints it
  (`Medium: ...`); US spellings throughout; the MakerWorld quick start's
  preset table lists every preset of both files; the reference no longer
  cites two measuring scripts that are not in the repository; long table
  cells shortened to pass the docs gate.

### Removed

- `docs/Plug_Puller_Complete_Guide.pdf` (described the retired single-file
  model; replaced by the guide packets and the guides).
- The combined dial quick start and dial reference
  (`docs/guides/dial-quick-start.md`, `docs/guides/dial-reference.md`,
  `docs/Plug_Puller_Dial_Quick_Start.pdf`, `docs/Plug_Puller_Dial_Reference.pdf`,
  built earlier in this cycle) and `tests/test_dial_reference.py`:
  replaced by the per-tool packets before any release carried them.

## [0.12.0] - 2026-09-24

The two tools move into two files. The **one-sided puller** (the old
flat tool) stays in `src/Plug_Puller_Parametric.scad`; the **two-sided
puller** (the old heavy-duty clamshell) gets its own file,
`src/Plug_Puller_Two_Sided.scad`, with its own Customizer, a cradle for
rounded plugs, and both plates in one download.

### Added

- **`src/Plug_Puller_Two_Sided.scad`**: the two-sided puller in its own
  file, lifted out of the one-sided file without a geometry change
  (proven against the golden fixture). Its Customizer has four steps in
  plain words — Your Plug, Size, Attachment, Print Layout — and an
  `Advanced - Two-Sided Puller` section of 26 `plate_*` dials. Step 1
  takes the plug length (12–85 mm), its width at the prong end and at
  the cord end (`measure_plug_width_prong_end` / `_cord_end`, 5–40 mm:
  the size the two plates close across) and the cord (1.5–12 mm). The
  finger holes follow the shared size table: Ø 17.5 / 21 / 24 mm at
  Small / Medium / Large. Ships with `parameter_mapping_two_sided.json`
  (39 parameters) and `presets/Plug_Puller_Two_Sided.json` (the round
  extension cord and a measured USB-C laptop plug).
- **`dist/Plug_Puller_Two_Sided_SingleFile.scad`**: the two-sided
  puller as one file for web customizers; `scripts/build_flattened.py`
  builds both single files and `--check` verifies both.
- **`src/fit_sizes.scad`**: the Small / Medium / Large size table and
  finger clearance, shared by both files.
- **Both plates in one file**: `print_layout` (Step 4 of the two-sided
  file) is `Both plates` by default, two identical plates side by side,
  or `One plate`. The console says "PRINT LAYOUT: both plates side by
  side - flip one after printing".
- **Rounded or flat sides** (`plug_sides`, two-sided): `Rounded sides`
  (the default) gives each plate a sloped cradle, 2.5 mm per side
  (`plate_cradle_depth`), with 0.5 mm of room where the plates meet
  (`plate_grip_clearance`), so a round plug, a USB-C or charger tip
  centers itself; the teeth follow the slope and the arm tips step in
  to carry it. `Flat sides` keeps the straight toothed edge for a boxy
  plug.
- **See-through plug in the preview** (`show_plug_preview`, both files,
  on by default): a translucent plug built from your numbers sits in
  the pocket or on the plate so you can check the fit; it is never
  exported.
- **New in-model checks**: two-sided WC-12
  `PLUG NARROWER THAN THE CORD CHANNEL - ARMS CANNOT TOUCH IT` and
  WC-13 `CRADLE SHALLOWER THAN ASKED - PLUG NARROW`; one-sided W-20
  `PLUG THICKER THAN 24MM - USE THE TWO-SIDED PULLER FILE`. The
  two-sided file also echoes its derived values (plate length, grip
  gaps, cradle depth, cord channel, finger hole, strap slot, zip
  stations) to the console.
- **`export_card` selector on the measuring stencil** (`Measuring_Stencil.scad`,
  new `[Export]` Customizer tab): `All cards` keeps the normal packed-sheet
  layout, while picking a card ID (P1/P2/P3/R1/C1/F1/F2) renders just that one
  stencil at the origin so it can be uploaded as a standalone model. This is
  what lets the release build ship every card as its own file.
- **`scripts/build_release_stls.py`**: one command renders the entire
  committed ready-to-print library under `stl/` — 9 plug tools (6
  one-sided pullers for the lamp and standard plugs and 3 two-sided
  pullers for the round extension cord, each × Small/Medium/Large) and
  16 measuring-stencil cards (Visual/Tactile full sets plus every
  individual card) — each watertight-checked. `--only plug-puller` /
  `--only stencil` rebuild one group.
- **`stl/README.md`**: an index of the library that maps every file to the
  plug family, hand size, and stencil card it prints.

### Changed

- **Reorganized `stl/` into a self-describing tree** so there is a single,
  unambiguous home for downloads. The old flat, default-plug samples
  (`stl/Plug_Puller_{Small,Medium,Large}.stl`,
  `stl/Measuring_Stencil{,_Tactile}.stl`) are replaced by
  `stl/Plug-Puller/…` and `stl/Measuring-Stencil/{Visual,Tactile}/…`, whose
  filenames name the plug preset, size, and stencil card. README and the
  beginner guides now link the new paths.
- **`tests/test_shipped_stls.py`** guards the whole library by reusing
  `build_release_stls.py`'s job catalog: every shipped STL is checked
  watertight (quick lane) and re-rendered mesh-equivalent to its source
  (render lane), so the downloads can never silently drift from the model.
- **The round extension cord ships as the two-sided puller**:
  `stl/Plug-Puller/Plug-Puller_Two-Sided_Round-Extension-Cord-NEMA-5-15_{Small,Medium,Large}.stl`,
  each file holding both plates (each plate the same as before). Flip
  one after printing, then zip-tie the pair face to face around the
  plug.
- **One-sided Step 1 names**: `measure_plug_width_prong_end` /
  `_cord_end` and `measure_plug_thickness_prong_end` / `_cord_end`
  replace the `…_wall` / `…_cable` names, and the help texts name the
  prong end and the cord end. Saved parameter sets that use the old
  names need the new ones. Slider ranges: width 8–38 mm, thickness
  4–40 mm, cord 1.5–9 mm, length 12–85 mm.
- **One-sided Customizer**: Step 1 comes first (Step 0 is gone), and
  the sections read `Step 4 - Cord Hook`, `Advanced - Zip Tie
  Placement` and `Advanced - Velcro Placement` (no "- Flat Tool"); the
  Step 3, Step 4 and Advanced placement help texts describe the one
  tool.
- **Two-sided strap slot**: with Auto placement a plug too short for a
  velcro slot now gets none, with an orange preview note
  `STRAP SLOT LEFT OUT - PLUG TOO SHORT FOR ONE`, instead of a red tag;
  WC-7 and WC-11 fire only with Manual placement.
- **Two-sided tags name the width**: WC-2
  `PLUG TOO WIDE - ARMS BULGE PAST FINGER LOBES` and WC-9
  `PLUG WIDTH TAPER LOOKS WRONG - RECHECK BOTH ENDS`.
- **`plate_grip_bite`** (was `clam_grip_bite`) applies to `Flat sides`
  and the plug preset only, and WC-3 fires only there.
- **Two-sided finger holes use the true size table**: Large is Ø 24 mm
  (the old file's auto-fit clamp shrank it to 22.66 mm at its default
  plug).
- **Outline sheets**: the sheets say "One-sided puller" and "Two-sided
  puller plate", and the plate sheets are
  `outline_two-sided-plate_{small,medium,large}.svg`: 9 sheets and a
  10-page PDF.
- **README, starter guide, beginner quick start** (and the starter
  guide PDF) describe the two tools, which file to open for each, and
  the two-sided steps.

### Removed

- **Step 0 `tool_style` and the clamshell in the one-sided file**
  (`src/Plug_Puller_Parametric.scad`): its Advanced clamshell section,
  the clamshell checks and the `Clamshell Plate` render mode. The
  two-sided puller lives in `src/Plug_Puller_Two_Sided.scad`.
- **Two-sided attachment choices `Velcro strap` and `None`**: without
  zip ties the two plates cannot be held together.
- **`Plug-Puller_Heavy-Duty-Cord-NEMA-5-15_Clamshell-Plate_{Small,Medium,Large}.stl`**,
  replaced by the two-sided files above.
- **The one-sided saved set "Heavy-duty round cord (NEMA 5-15)"**; the
  two-sided presets file has the round extension cord.
- **The `clamshell_plate` golden fixture**; the `two_sided_plate`
  fixture covers the plate.
- **The three one-sided outline sheets for the extension-cord plug**:
  that plug's sheets are the three two-sided plate sheets.
- **`dist/Plug_Puller_SingleFile.json`**: a stray file of Customizer
  sets saved in 0.8.0 that named settings which no longer exist.

## [0.11.0] - 2026-07-23

Makes the measuring stencil work one-handed on an installed cord (the
gauges open through the card edge) and fully non-visual: a Tactile
label mode with raised ADA-size characters and a fold-flat Grade 2
braille title flap on every card.

### Added

- **Tactile label mode** (`label_mode = Tactile`, new `[Labels]`
  Customizer tab with a `Visual (default)` / `Tactile (raised +
  braille)` preset pair in `Measuring_Stencil.json`, pre-rendered
  `stl/Measuring_Stencil_Tactile.stl`): every debossed label becomes a
  raised uppercase character at ADA 703.2 size (16 mm nominal, 0.8 mm
  proud), and every card grows a **Grade 2 braille title flap**
  (ADA 703.3) past its top edge. The flap prints leaning back at 75° —
  the CHI 2024 sweet spot where braille dots print crispest — joined
  to the card by a living hinge (`hinge_thickness`, the only other new
  parameter) and held by break-away support fins with snap-off bridges
  and a bed brim (the braille-wedge-card technique). Post-print: snap
  the fins off and fold each flap away from the card until flat — the
  braille lands face-up beyond the card's top edge. Tactile R1 drops
  the numerals (an ADA digit cannot fit the 10 mm tick pitch) and C1's
  slot pitch widens so the ADA digits stay separated; the sheet packer
  accounts for every flap's printed footprint.
- **Braille translation pipeline**
  (`scripts/generate_braille_labels.mjs` + committed
  `scripts/braille_labels.json`): card titles pre-translated to UEB
  Grade 2 Unicode braille with Liblouis
  (`unicode.dis,en-ueb-g2.ctb`), hardcoded into the SCAD as
  `BRAILLE_LABELS` — no user-facing braille settings.
  `tests/test_braille_labels.py` drift-locks the SCAD copy against the
  generator output, validates every codepoint is Unicode braille, and
  asserts every line fits its card's width.
- **Shipped-STL coverage**: `stl/Measuring_Stencil_Tactile.stl` joins
  the watertight/winding guards, and the stencil render-parity test is
  parametrized over both label modes (the Tactile case doubles as the
  render smoke test for the new geometry).

### Changed

- **C1 cord gauge is now open-throat** (both label modes): the Ø 3–9 mm
  through-holes became U-slots opening through the card's bottom edge,
  so the card slides sideways onto an *installed* cord — no free cord
  end needed. Usage is now "the smallest slot that slips over the cord
  is the cord thickness".
- **P1–P3 cord holes opened the same way**: each plug card's round
  cord hole gained a channel through the bottom edge (the numeric cord
  caption moved just left of the channel in Visual mode).
- **README, starter guide, measuring guide, and outlines guide**
  updated for the open-slot gauge usage, the two label-mode presets
  (ADA 703 naming: modes named by modality, Visual/Tactile), the
  Tactile post-print fold steps, and a hinge material note (PETG/PP
  folds more reliably than PLA; fold once, gently).

## [0.10.0] - 2026-07-23

Makes Step 3 shape both tools, replaces the finger stencil with a full
measuring kit (match your plug by touch or measure it), and adds a
single starter guide — with a printable PDF that carries its own 1:1
paper stencil — as the one page to start from.

### Added

- **Measuring stencil** (`Measuring_Stencil.scad`, pre-rendered
  `stl/Measuring_Stencil.stl`): the finger-sizing stencil grown into a
  full measuring kit of thin cards, each with a raised two-letter ID
  readable by touch — P1/P2/P3 plug silhouette cards (width + thickness
  cutouts and a cord hole per Step 1 preset: hold your plug in the
  opening, no ruler needed), R1 tactile ruler (raised mm ticks,
  debossed numerals, edge notches every 10 mm), C1 cord gauge
  (Ø 3–9 mm holes), and F1/F2 finger cards (the 18 labeled holes,
  Ø 15–25 / Ø 26–32). Customizer `bed_width` / `bed_depth` /
  `part_index` split the cards onto print sheets automatically for
  small printers (console echoes the sheet map; oversize cards are
  reported and isolated). Preset dimensions are drift-tested against
  the main model by `tests/test_stencil_data.py`.
- **Starter guide** (`docs/guides/starter-guide.md`): the single
  entry-point walkthrough — Path A "match a preset with the stencil
  cards" / Path B "measure with R1/C1/F1/F2", the stencil card legend,
  the Customizer steps, and a per-step map of which tool each step
  shapes. Ships as a printable PDF
  (`docs/Plug_Puller_Starter_Guide.pdf`, built by
  `scripts/build_starter_guide_pdf.py`) whose last page is a 1:1 paper
  stencil sheet (`docs/guides/stencil-sheet.svg`, generated by
  `scripts/generate_stencil_sheet.py`) — calibration square, P1–P3
  silhouettes, 100 mm ruler, and finger circles for people without a
  3D printer.
- **Clamshell Step 3 wiring**: the Step 3 Attachment dropdown now
  shapes the heavy-duty clamshell too — `Zip ties` / `None` remove the
  velcro strap slots, `Velcro strap` / `None` remove the zip stations,
  and `strap_width` widens the arm slots (up to the arm window). Two
  new in-model warnings: WC-10 (zip stations disabled by Step 3 — the
  zip ties are what hold the two plates together) and WC-11 (strap
  wider than the arm slot window). Covered by a new render test
  (`tests/test_clamshell_attachment.py`).

### Changed

- **Customizer copy**: every step tab now says which tool it shapes —
  Step 4 renamed to "Cord Hook - Flat Tool", `velcro_style` labeled
  flat-tool-only, `strap_width` documented for both tools, and the
  console echoes the resolved tool plus which settings it ignores.
- **README / guides** repointed at the new starter guide as the
  primary path; all finger-stencil references updated to the
  measuring stencil.

### Removed

- **Root wrapper `Plug_Puller.scad`**: open
  `src/Plug_Puller_Parametric.scad` directly (the wrapper confused
  "which file do I open?" and broke Customizer dropdowns in some
  builds when opened from the root).
- **`Finger_Sizing_Stencil.scad`** and `stl/Finger_Sizing_Stencil.stl`
  — superseded by the measuring stencil (its F1/F2 cards carry the
  same 18 holes).

## [0.9.0] - 2026-07-23

One step from the **v1.0 public milestone**: the release that makes the
public repo self-validating (tests + CI), zero-install customizable
(browser path), and illustrated (guide photos).

### Added

- **Engineering pipeline** ported from the development repo: the full
  pytest suite (7 golden STL fixtures rendered from `src/` with
  OpenSCAD 2026.01.03 + Manifold, mesh comparison via trimesh,
  Customizer hygiene / preset routing / fit-derivation / parameter
  schema / flattened-build parity tests), the `stl-validation.yml`
  GitHub Actions workflow (lint → quick tests → full render validation
  → fixture integrity), and the build scripts
  (`scripts/build_flattened.py`, `scripts/generate_outline_sheets.py`,
  `scripts/build_outline_sheets_pdf.py`,
  `scripts/regenerate_fixtures.py`). Fixtures are plain committed STLs
  — no Git LFS needed to clone or run CI.
- **Mesh-health guards**: `tests/test_shipped_stls.py` pins every
  shipped STL as watertight/winding-consistent and keeps the Small /
  Medium / Large downloads mesh-equivalent to their golden fixtures;
  `tests/test_preset_renders.py` renders every saved parameter set and
  fails on any `WARNING:`/`undefined` console output or non-watertight
  mesh. Audit confirmed all shipped meshes healthy and all presets
  warning-free.
- **Zero-install web customizer path**: `docs/guides/web-customizer.md`
  walks through customizing in the browser via the OpenSCAD Playground
  (loading `dist/Plug_Puller_SingleFile.scad` from the repo), with a
  manual load fallback and phone usage notes; the README links it
  prominently ("Customize in your browser — no install").
- **MakerWorld listing draft** (`docs/makerworld-listing.md`): full
  Parametric Model Maker listing text and publish checklist, gated
  behind an explicit maintainer licensing decision (MakerWorld
  platform grant alongside PolyForm NC 1.0.0, or stay
  playground-only).
- **Guide photos and preview renders** (`docs/images/`): real photos of
  the printed heavy-duty clamshell (plates, zip-tie assembly,
  assembled, in use at an outlet) embedded in the quick-start and
  measuring guides plus a README hero shot, and fresh OpenSCAD preview
  renders (Medium flat tool with the green confirmation tag, clamshell
  plate).
- **Try-before-you-print outline sheets**
  (`docs/guides/outline-sheets/`, 12 SVGs): a printable 1:1
  dimensioned silhouette of every quick-select combination — the three
  `plug_preset` families × Small / Medium / Large for the flat tool,
  plus the heavy-duty clamshell plate at all three sizes. Each sheet
  has CAD-style dimension lines, a 50 × 50 mm calibration square, the
  matching Customizer settings in the title block, and a how-to strip.
  Guide: `docs/guides/print-preview-outlines.md`. All twelve sheets are
  also bundled as one printable PDF with a cover index
  (`docs/Plug_Puller_Outline_Sheets.pdf`), page size 210 × 279 mm so it
  prints 1:1 on both A4 and US Letter.
- **Finger-sizing stencil** (`Finger_Sizing_Stencil.scad` at the repo
  root, pre-rendered `stl/Finger_Sizing_Stencil.stl`): a thin
  parametric plate with the measuring template's 18 finger-sizing
  circles (Ø 15–32 mm) as labeled through-holes — the no-scissors way
  to find `measure_finger_width`. A `split_halves` option splits it
  into two smaller plates for tight beds.
- README, measuring guide, and quick-start cross-links to the new
  sheets and stencil.

## [0.8.0] - 2026-07-22

First public release.

### Added

- Unified two-tool parametric model behind a Step 0 `tool_style`
  selector:
  - **Flat tool** — a slab with a taper-aware two-level plug pocket
    whose side walls follow a parametric plug side rail, rail-placed
    zip-tie holes and velcro slots, mirrored finger holes, a chiral
    J-hook cord catch, and a plug wall notch.
  - **Heavy-duty clamshell** — two identical serrated collar plates
    that zip-tie face to face around a thick extension-cord plug.
  - `Auto from plug` picks the right tool from the plug measurements.
- Measurement-first Customizer: numbered Steps 0–4 for beginners,
  `Advanced -` sections for power users, `(Custom size only)` sections
  for experts.
- `plug_preset` quick-select calibrated to three reference plugs
  (2-prong lamp NEMA 1-15, standard 3-prong NEMA 5-15, heavy-duty
  round NEMA 5-15) plus `Measure my plug` manual entry.
- Sizes `Small` / `Medium` / `Large` grounded in ANSUR-II hand
  anthropometry, plus `Measure my hand` and full `Custom` unlock.
- Auto-fit bounds clamping and in-model validation warnings (flat tool
  W-1…W-19, clamshell WC-1…WC-9) printed as red tags next to the part.
- Flattened single-file build (`dist/Plug_Puller_SingleFile.scad`) for
  MakerWorld Parametric Model Maker and other web customizers.
- Example saved parameter sets (`presets/Plug_Puller_Parametric.json`)
  and a machine-readable parameter schema (`parameter_mapping.json`,
  103 parameters).
- Beginner guides (quick start, measuring guide with printable 1:1
  template, fit troubleshooting), a power-user guide, printable PDF
  guides, and a full engineering reference
  (`docs/Plug_Puller_Reference.md`).
- Ready-to-print Small / Medium / Large sample STLs in `stl/`.

[0.14.0]: https://github.com/BrennenJohnston/openscad-plug-puller/releases/tag/v0.14.0
[0.13.0]: https://github.com/BrennenJohnston/openscad-plug-puller/releases/tag/v0.13.0
[0.12.0]: https://github.com/BrennenJohnston/openscad-plug-puller/releases/tag/v0.12.0
[0.11.0]: https://github.com/BrennenJohnston/openscad-plug-puller/releases/tag/v0.11.0
[0.10.0]: https://github.com/BrennenJohnston/openscad-plug-puller/releases/tag/v0.10.0
[0.9.0]: https://github.com/BrennenJohnston/openscad-plug-puller/releases/tag/v0.9.0
[0.8.0]: https://github.com/BrennenJohnston/openscad-plug-puller/releases/tag/v0.8.0

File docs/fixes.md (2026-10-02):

# Fix Log

## 2026-09-30: the check script could not pass a text value with spaces

**The bug.** `scripts/scad-check.ps1 -Defines` could not check the model with a setting whose value has spaces, such as `size="Measure my hand"` or a plug preset name. Windows PowerShell strips the quotes from such a value twice: when it starts the script with `-File`, and again when the script hands the value to OpenSCAD. OpenSCAD then received `size=Measure my hand`, reported a syntax error on the file's last line, and the check failed however the quotes were written. Fixing that showed a second gap: OpenSCAD does not test a text value against the setting's dropdown list, so a misspelled choice passed the check while the model quietly used its default numbers.

**The fix.** The script now adds the quotes itself when a text value arrives without them, and starts OpenSCAD with a command line it builds by the rules programs use to split one, so no quote is lost on the way. Before OpenSCAD runs, the script reads the setting's dropdown list from the `.scad` file and prints a `WARNING:` line when a text value is not one of the choices, which fails the check. Numbers, `true` and `false`, lists and a run with no settings work as before.

**The check that passed.** From Windows PowerShell and from Git Bash, on `src/Plug_Puller_Parametric.scad`: `-Defines 'size=Measure my hand'` and `-Defines 'size="Measure my hand"'` both print "Derived values for size 'Measure my hand'" and CHECK PASSED; `-Defines 'plug_preset=Standard 3-prong plug - NEMA 5-15'` changes the pocket depth from 25.5 to 46.2 mm; `-Defines 'measure_plug_length=40'` gives a pocket depth of 40 mm; `-Defines 'size=Nonsense size'` prints the warning and CHECK FAILED; and with no `-Defines` the check passes as before.

A known limit, not changed: when PowerShell starts the script with `-File`, several settings given as `'a','b'` arrive joined into one, so give one setting per run there.

## 2026-10-01: the guides printed "{step4}" instead of the fourth step's name

**The bug.** All four documents, the quick starts and the full guides of both tools, as pages and as PDFs, ended a sentence in their Get the file section with "then {step4}" instead of "then Step 4 - Cord Hook" (one-sided puller) or "then Step 4 - Print Layout" (two-sided puller), and a screen reader read the braces aloud. The guide builder fills a source file's `{name}` placeholders from a table, and an unknown name stops the build. The pattern that finds them in `scripts/guide_text.py` accepted letters and underscores only, so a name with a digit, like `step4`, was neither filled nor reported. No release carried it.

**The fix.** The pattern now accepts a name that starts with a letter or an underscore and goes on with letters, digits or underscores, so `{step4}` is filled like every other placeholder, and an unknown name with a digit stops the build. A quick-lane test loads every guide source for both tools and fails if any `{name}` is left unfilled. All four documents are rebuilt; each PDF changes on one page.

**The check that passed.** `tests/test_guide_text.py::test_every_source_fills_for_both_tools` failed before the change ("unfilled ['{step4}']") and passes after it. After rebuilding the four documents, `{step4}` appears under `docs/guides` only in its source file, `docs/guides/source/get-the-file.md`. The builders' PDF checks pass with 15, 88, 13 and 54 pages, as before. The quick lane passes (243) and `scripts/check_docs.py` is clean.

## 2026-10-01: an outline sheet's zip-tie spacing label could read negative

**The bug.** On a one-sided outline sheet, the label between the top two zip-tie holes printed the signed difference between their positions, so it read negative whenever the sheet generator found the right-hand hole first. The committed lamp-plug sheets read "-20.5" (Medium) and "-17.71" (Small), and regenerating the sheets for 0.14.0 would have added "-20.54" (lamp, Large) and "-30.98" (wide appliance plug, Large). The vertical label beside it already printed the plain distance.

**The fix.** `scripts/generate_outline_sheets.py` prints the plain distance for that label too. All 21 sheets and the outline sheets PDF are regenerated. A quick-lane test, `tests/test_outline_sheets.py`, fails if any label on any sheet starts with a minus sign.

**The check that passed.** The new test failed before the change on the two committed lamp sheets and passes after it. The four labels read 17.71, 20.52, 20.54 and 30.98, each equal to the length of its drawn line. All 21 sheets pass the generator's parity checks, the PDF passes its own checks (22 pages, the title, 31 bookmarks), the quick lane passes (250) and `scripts/check_docs.py` is clean.

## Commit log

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2026-07-23 Port engineering pipeline from the dev repo
    Bring over the pytest suite (7 golden fixtures + 7 test modules with
    shared runner/comparator helpers), the STL-validation CI workflow, and
    the build scripts (flattened single-file build, outline sheets + PDF,
    fixture regeneration), adapting all paths to this repo's layout
    (src/, dist/, presets/, root parameter_mapping.json).
    Golden fixtures are regenerated in-place against src/ with OpenSCAD
    2026.01.03 (Manifold) and committed as plain STLs - no Git LFS - so
    clones and CI need no extra tooling. Includes the idealized clamshell
    reference plate so the clamshell parity tests run instead of skipping.
    Full suite green locally: 99 passed (quick + rend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
    [Plug Puller_3_Prong_Idealized_Sample_Plug_Bottom.stl]
2026-07-23 Add mesh-health guards for shipped STLs and Customizer presets
    Audit result: all four shipped STLs (Small/Medium/Large flat tools +
    finger-sizing stencil) are watertight with consistent winding, the size
    STLs are mesh-identical to their golden fixtures, and every saved preset
    renders warning-free — the v5-era non-watertight minkowski meshes and
    `-undefined` echo bugs do not reproduce in the current model.
    Encode those checks as permanent tests so CI guards them:
    - tests/test_shipped_stls.py — watertight/winding checks on stl/*.stl
    (quick lane), drift guard pinning the shipped size STLs to the golden
    fixtures, and a stencil render-parity test (render lane).
    - tests/test_preset_rende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
2026-07-23 Add guide photos and model preview renders
    Resolve the bulk of the TODO(photos) markers in the beginner guides:
    - docs/images/: four real device photos of the heavy-duty clamshell
    (plates + plug, zip-tie assembly, assembled, in use at an outlet)
    plus two fresh OpenSCAD CLI preview renders (default Medium flat tool
    showing the green confirmation tag, and the clamshell plate).
    - quick-start-beginner.md: clamshell renders/photos at Step 0, the
    green-tag preview under "How to know it worked", and the assembly +
    in-use photo sequence in Step H.
    - measuring-guide.md: assembled-clamshell photo beside the two-tools
    note and the zip-tie threading photo in the round-plug tip.
    - README: in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
2026-07-23 Release 0.10.0
    Wire Step 3 Attachment into the heavy-duty clamshell and clarify which
    step shapes which tool; replace the finger stencil with a full measuring
    stencil (P1-P3 plug silhouettes, R1 ruler, C1 cord gauge, F1/F2 finger
    cards, embossed IDs, auto bed-splitting); ship a consolidated starter
    guide with a 1:1 printable PDF alternative; and remove the confusing
    root wrapper Plug_Puller.scad.
    [Finger_Sizing_Stencil.scad, Finger_Sizing_Stencil.stl, Measuring_Stencil.scad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]
2026-07-24 Release 0.11.0
    Open-throat cord gauge: C1 and the P cards' cord holes now open through the bottom edge so the cards slide sideways onto an installed cord. New Tactile label mode (label_mode + hinge_thickness, Customizer preset pair): raised ADA 703.2 characters plus a fold-flat Grade 2 braille title flap on every card, printed at 75 deg behind break-away fins. Braille pre-translated with Liblouis (UEB Grade 2) via scripts/generate_braille_labels.mjs and drift-locked by tests/test_braille_labels.py; shipped STL guards extended to the new Measuring_Stencil_Tactile.stl.
    [Measuring_Stencil.scad]
2026-07-24 Reorganize STL library into a self-describing stl/ tree
    Consolidate the ready-to-print downloads into one place so there are no
    longer duplicate STL copies in multiple locations. The old flat
    default-plug samples (stl/Plug_Puller_{Small,Medium,Large}.stl and
    stl/Measuring_Stencil{,_Tactile}.stl) are replaced by a preset-based
    library whose filenames name the plug preset, hand size, and stencil card:
    stl/Plug-Puller/ 9 tools = 3 plug presets x 3 hand sizes
    stl/Measuring-Stencil/ Visual/ and Tactile/ card sets (All-Cards + P1-F2)
    stl/README.md index of the whole library
    - Add the export_card selector to Measuring_Stencil.scad so each stencil
    card can be rendered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
    [Measuring-Stencil_Visual_C1_Cord-Gauge.stl, Measuring-Stencil_Visual_F1_Finger-Sizing-15-25mm.stl, Measuring-Stencil_Visual_F2_Finger-Sizing-26-32mm.stl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]
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2026-09-23 Move the size table into src/fit_sizes.scad (R1 A1)
    The two-sided puller is about to get its own file and needs the hand-size
    table and the finger clearance without the one-sided derivation layer.
    Move FIT_GRIP_CLEARANCE and the Small/Medium/Large size table verbatim
    into a small hidden include, include it first from the one-sided file,
    teach build_flattened.py the third include, regenerate dist/, and extend
    the include-order test. No geometry changed: all seven golden fixtures
    match their references in volume, area and bounds to 6 decimals.
    Claude-Session: https://claude.ai/code/session_01RpuGKb6VwWZw57JNE9DH9E
    [Plug_Puller_Parametric.scad, Plug_Puller_SingleFile.scad, fit_measured.scad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]
2026-09-23 Extract the two-sided puller into its own file (R1 A2)
    The clamshell moves into src/Plug_Puller_Two_Sided.scad as a verbatim
    copy of the unified model's clamshell parameters, derived values,
    warnings and modules, with only the inputs it reads. The finger bore now
    comes straight from the size table in fit_sizes.scad instead of the
    one-sided auto-fit clamp. plug_preset offers only the heavy-duty preset
    the routing prefills, and size drops Custom.
    A new two_sided_plate fixture (a byte copy of clamshell_plate) and
    tests/test_two_sided_parity.py prove the heavy-duty preset plate is the
    same as the fixture and as the unified file's render (volume, area and
    bounds to 6 decimals). The clamshell par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
    [Plug_Puller_Two_Sided.scad, reference.stl]
2026-09-24 Build a second single-file artifact for the two-sided puller (R1 A3)
    scripts/build_flattened.py now builds every artifact in BUILDS: the
    one-sided puller (fit_sizes + fit_measured + presets inlined) and the
    two-sided puller (fit_sizes inlined) into
    dist/Plug_Puller_Two_Sided_SingleFile.scad, with the same safety rails,
    a per-build header, and --check covering both. The old names stay as
    aliases for the first build. The one-sided artifact changes only in its
    header paragraph.
    tests/test_flattened_build.py runs the static checks for both artifacts
    and adds a render test: the flattened two-sided file renders the
    two_sided_plate fixture's plate to 6 decimals.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
    [Plug_Puller_SingleFile.scad, Plug_Puller_Two_Sided_SingleFile.scad]
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2026-09-24 Leave the strap slot out of short two-sided plates, warn on thin plugs (R1 B2)
    On a short plug the strap slot used to run into the zip-tie holes and
    print two red tags (the owner's 23 mm USB-C plug lost two of its six
    holes). In Auto placement the slot is now left out when its window
    cannot take the strap, and a preview-only orange note says so; the slot
    is never wider than it is long. Manual placement keeps the slot and its
    collision tags.
    A plug narrower than the cord channel's floor now gets the red tag
    "PLUG NARROWER THAN THE CORD CHANNEL - ARMS CANNOT TOUCH IT" instead of
    silently loose arms, and every render prints the derived values (plate
    length, grip gaps, cord channel, finger hole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
    [Plug_Puller_Two_Sided.scad, Plug_Puller_Two_Sided_SingleFile.scad]
2026-09-24 Export both two-sided plates in one file (R1 B3)
    The two-sided puller is two identical plates, and the person who printed
    one for the owner's USB-C plug did not expect to print it twice. With the
    default print_layout "Both plates" the file now exports both plates side
    by side, outer face down with an 8 mm gap, and the console says to flip
    one after printing; "One plate" still exports a single plate. The hidden
    render_mode is now Full / One plate, and the fixture, the tests and the
    outline-sheet jobs render the single plate from the two-sided file.
    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
    [Plug_Puller_Two_Sided.scad, Plug_Puller_Two_Sided_SingleFile.scad]
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2026-09-24 Name the plug's width in two two-sided red tags (R1 Gate B, Q-21)
    The two-sided file measures the plug's width across the arms, but two of
    its red tags still said thick: WC-2 now reads "PLUG TOO WIDE - ARMS BULGE
    PAST FINGER LOBES" and WC-9 "PLUG WIDTH TAPER LOOKS WRONG - RECHECK BOTH
    ENDS", as the owner chose at Q-21. A render test pins both tags and
    checks that no two-sided tag calls the plug thick.
    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
    [Plug_Puller_Two_Sided.scad, Plug_Puller_Two_Sided_SingleFile.scad]
2026-09-24 Take the clamshell out of the one-sided file; add W-20 (R1 C1)
    The one-sided file now builds only the one-sided puller. Step 0 and
    tool_style, the clamshell dials, derived values, checks, warnings and
    modules, and the "Clamshell Plate" render mode are gone (2,569 to 2,033
    lines). A plug 24 mm or thicker gets the new red tag "PLUG THICKER THAN
    24MM - USE THE TWO-SIDED PULLER FILE" instead of a silent switch. The six
    flat fixtures render identical to 6 decimals.
    The parameter mapping drops tool_style and the 24 clam_* rows (78
    remain), the clamshell_plate fixture is deleted (two_sided_plate guards
    that plate), and the parity test checks the two-sided file alone. To keep
    the checks true, the h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
    [Plug_Puller_Parametric.scad, Plug_Puller_SingleFile.scad, reference.stl]
2026-09-24 Name the one-sided Step 1 measurements by prong end and cord end (R1 C2)
    The one-sided file's four plug measurements now use the same words as the
    two-sided file, as the owner chose at Q-15: measure_plug_width_prong_end
    and _cord_end, measure_plug_thickness_prong_end and _cord_end. The rename
    reaches the mapping, the saved presets, the measured_hand fixture's keys,
    the Python formula mirror and its tests, and the outline script; the
    internal _eff_* names and every value stay the same, and the six flat
    fixtures render identical to 6 decimals.
    The sliders and their W-1 plausibility windows take the owner's ranges
    from Q-16 (width 8-38, thickness 4-40, cord 1.5-9, length 12-85), and the
    Step 1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
    [Plug_Puller_Parametric.scad, Plug_Puller_SingleFile.scad]
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2026-09-24 Describe two tools in two files in the front-door docs (R1 D2)
    README, the starter guide and the beginner quick start now say which
    file to open for which plug (the one-sided puller or the two-sided
    puller), give each file's four steps, explain Rounded and Flat sides,
    and link both single files and the pair STLs. CHANGELOG [Unreleased]
    lists every change of this round so far.
    The starter guide PDF keeps its own copy of the text in
    scripts/build_starter_guide_pdf.py, so that copy now follows the new
    guide too, including the open-slot cord gauge; slightly tighter table
    cells keep page 1 clear of its footer. The PDF is rebuilt.
    Claude-Se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
2026-09-24 Measure the middle finger; fix a gallery alt text (R1 Gate D, Q-28)
    The MakerWorld quick start told people to measure their index finger
    for measure_finger_width. The help text in both model files and the
    measuring guide say the widest knuckle of the middle finger, the finger
    that goes in the pull hole.
    The listing's gallery item 5 alt text gave each plate one finger lobe
    and three zip-tie slots. A plate has two finger holes, two serrated
    arms and six zip-tie holes. The new words are the ones the maintainer
    approved at Gate D.
    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
2026-09-25 Name one version, 0.12.0, everywhere the project states it
    The README badge said 0.10.0, its milestone note 0.10, the project
    facts v0.11.0 and the outline sheets' footer v0.9. All now say 0.12.0,
    and the CHANGELOG's [Unreleased] section becomes [0.12.0] - 2026-09-24
    with its release link. The sheets and their PDF were regenerated with
    the scripts, so only the footer changes on the three plate sheets; the
    six one-sided sheets also redraw their dashed-line render noise, with
    every cut line unchanged.
    Claude-Session: https://claude.ai/code/session_018V7Qn11QEq3dyoiBahQPNS
2026-09-25 Say 0.12.0 in the one-sided file's header; drop "flat tool" from two help texts
    The version bump (pull request #8) missed the one place a source file
    states the version: src/Plug_Puller_Parametric.scad line 1 still said
    "Plug Puller 0.9". It now says 0.12.0, like the badge, the project
    facts, the outline sheets and the CHANGELOG.
    Two Customizer help texts in the one-sided file, for zip_placement and
    velcro_placement, still said "the flat tool's". R1's retired-word
    searches covered only Markdown, so these two lines were never checked.
    They now say "the tool's", the wording S-63 chose for hook_hand's help
    in the same file. The two-sided file had no such line.
    dist/Plug_Puller_SingleFile.scad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
    [Plug_Puller_Parametric.scad, Plug_Puller_SingleFile.scad]
2026-09-26 Give the two-sided puller the USB-C, lamp and standard presets, each with its own sides
    The two-sided plug_preset dropdown now offers, after the unchanged
    heavy-duty extension cord, the USB-C laptop tip (23 / 13 / 13 / 7 mm,
    Rounded sides with the cradle the owner printed and tested), the flat
    2-prong lamp plug (37 / 25 / 11.2 / 3.6 mm, Flat sides) and the standard
    3-prong plug (46.2 / 26.6 / 13.4 / 7.0 mm, Flat sides): the plugs chosen at
    R2's Gate A. A per-preset sides value replaces the rule that forced every
    preset to Flat sides, so a preset can carry the cradle; the heavy-duty
    plate is unchanged to 6 decimals (volume, area, bounds) and still matches
    its golden fixture. The lamp and stan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
    [Plug_Puller_Two_Sided.scad, Plug_Puller_Two_Sided_SingleFile.scad]
2026-09-26 Give the one-sided puller the wide 2-prong appliance plug preset; fix two stale mapping facts
    The one-sided plug_preset dropdown gains "Wide 2-prong appliance plug -
    NEMA 1-15" (38 long, 34 wide and 16 thick at both ends, 5 mm cord: the
    owner's measured vacuum-plug set), the plug chosen at R2's Gate A for
    this file. The six preset ternaries carry its numbers; it renders clean
    (the pocket auto-fits from 40.7 to 37.8 mm wide, 3.8 mm wider than the
    plug); the three existing presets are unchanged to 6 decimals.
    parameter_mapping.json no longer claims a generator script that does not
    exist, and quality's unit is "segments", not "mm". One saved set named as
    the label; the single-file build regene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
    [Plug_Puller_Parametric.scad, Plug_Puller_SingleFile.scad]
2026-09-26 Add the P4 stencil card for the wide 2-prong appliance plug, with its braille flap
    Measuring_Stencil.scad gains a fourth plug gauge card, P4 (38 long, 34
    wide, 16 thick, 5 mm cord: the preset added in the previous commit), in
    both label modes. The fixed card list is index-driven now (N_PLUG and
    the I_R1 ... I_F2 indices), so the ruler, cord gauge and finger cards
    shift behind the P cards without hand-edited numbers. The Tactile flap
    reads "wide plug" / "2 prong" in UEB Grade 2, translated by the existing
    Liblouis generator (9 and 7 of the card's 10 cells); no braille geometry
    constant changed.
    The release library gains the two P4 files and re-renders the two
    All-Cards files (the other 14 st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
    [Measuring-Stencil_Tactile_P4_Wide-2-Prong-Appliance-Gauge.stl, Measuring-Stencil_Visual_All-Cards.stl, Measuring-Stencil_Visual_P4_Wide-2-Prong-Appliance-Gauge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]
2026-09-26 Ship every preset as ready-to-print STLs and 1:1 outline sheets; sheets show the built pocket width
    The release library grows from 9 to 21 plug tools: a preset now ships from
    every file that offers it (the lamp and standard plugs as two-sided pairs
    too, the USB-C laptop tip as a two-sided pair, the wide appliance plug as
    a one-sided tool), three sizes each. The nine existing files are unchanged
    (identical geometry; byte rewrites restored). The --help text names stl/.
    The outline sheets grow from 9 to 21 the same way, with a 22-page PDF.
    Each title block now says which file to open. Plate sheets name their plug
    in the title and read the strap slot from the mesh (none on a short plug)
    instead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
    [Plug-Puller_Two-Sided_Flat-2-Prong-Lamp-NEMA-1-15_Large.stl, Plug-Puller_Two-Sided_Flat-2-Prong-Lamp-NEMA-1-15_Medium.stl, Plug-Puller_Two-Sided_Flat-2-Prong-L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]
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2026-09-26 Put the README in the OpenAT order, add the manifest and the docs gate, sweep the wording
    README.md: Overview (the hero photo, the two guides first), How to obtain the
    device, Build instructions, How to use it, How to improve this device, Files,
    License, Attribution; every old sentence that still holds moved under a heading.
    okh.yml: an Open Know-How manifest in the Click Me manifest's field set, from
    public repository facts only.
    scripts/check_docs.py + tests/test_docs_gate.py: one H1, no skipped level, alt
    text on every image, no "click here" / "check the console", cells of at most 22
    words, no banned, hedging or retired words, every relative link resolving, no
    compliance claim. The test f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
    [Plug_Puller_Parametric.scad, Plug_Puller_SingleFile.scad]
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2026-09-29 Round the edges from stacked layers, so a browser previews each tool in seconds
    The rounded edges were minkowski() with a sphere. The WebAssembly build of
    OpenSCAD that browsers run cannot compute that its fast way: its CGAL hull
    fails and it falls back to a much slower method, so the Assistive Forge
    took 22 s to preview the one-sided puller from its link and 65 s for the
    two-sided plate, against 0.4 s and 1.3 s in desktop OpenSCAD.
    roundover_layers_3d() builds each rounded band from 0.1 mm layers, each the
    rolling ball's cross-section at the layer's top (offset(r = w) of
    offset(delta = -r) of the outline), so every step sits on or just inside
    the old surface: at most 0.09 mm inside, 0.1 to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
    [Plug-Puller_Flat-2-Prong-Lamp-NEMA-1-15_Large.stl, Plug-Puller_Flat-2-Prong-Lamp-NEMA-1-15_Medium.stl, Plug-Puller_Flat-2-Prong-Lamp-NEMA-1-15_Small.stl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]
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2026-10-01 List only the two-sided warning tags you can get, and tell MakerWorld readers why a short plug has no strap slot
    The two-sided full guide's red warning tags table no longer lists
    STEP 3 DISABLED ZIP HOLES - NOTHING SECURES THE TWO PLATES TOGETHER:
    every Step 3 choice keeps the zip ties, so the tag can never appear.
    The check stays in the model as a guard, and its comment now says why
    it cannot fire and why it stays. A comment-only change: the single-file
    build is regenerated, and the two-sided render is identical in volume,
    area and bounds to six decimals.
    The MakerWorld listing's two-sided Step 3 says that on a short plug,
    such as a USB-C tip, the strap slot is left out and the zip ties st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
    [Plug_Puller_Two_Sided.scad, Plug_Puller_Two_Sided_SingleFile.scad]
2026-10-01 Check text values with spaces, ship the STLs as binary files, and tighten the fixture comparison
    scripts/scad-check.ps1 can now check a setting whose value has spaces,
    such as a plug preset name. Windows PowerShell stripped the quotes twice,
    when it started the script with -File and when the script handed the
    value to OpenSCAD, so OpenSCAD stopped at a syntax error. The script now
    adds the quotes itself when they are missing and starts OpenSCAD with a
    command line it builds by the rules programs split one by. Because
    OpenSCAD never tests a text value against its dropdown list, the script
    also reports a value that is not one of the choices, which fails the
    check. Logged in docs/fixes.md.
    The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
    [Measuring-Stencil_Tactile_C1_Cord-Gauge.stl, Measuring-Stencil_Tactile_F1_Finger-Sizing-15-25mm.stl, Measuring-Stencil_Tactile_F2_Finger-Sizing-26-32mm.stl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]
2026-10-01 Make the dial texts say what the model does
    An audit of the 118 dial catalog rows against the model, the Customizer
    help texts and the pictures found three wrong texts and a few gaps, fixed
    here as the owner chose them:
    - The hook tip drop card promised that the dial sags the slot's mouth so
    a cord cannot back out; the model changes no shape, as the card's own
    note and the help text say. The card now says so.
    - The two-sided plug preset card spoke of one preset, "the measured
    heavy-duty cord plug"; the dropdown holds four, and each also sets the
    plug sides. The card now says "a measured reference plug" and "the
    sides".
    - The strap slot placement help said the Wing style always use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
    [Plug_Puller_Parametric.scad, Plug_Puller_SingleFile.scad]
2026-10-01 Point stale text at today's guides, title the outline sheets PDF, record the MakerWorld decision
    The one-sided plug preset help text and the file's opening comments name
    the quick start and the full guide instead of deleted guides; the
    measuring stencil's comments name the guides' card table and the paper
    stencil sheet; a one-sided red tag row no longer names a deleted guide.
    The README's preview note drops its version number, its first red tag row
    links both tools' tables, a credit that linked a private repository is
    gone, and it records the MakerWorld licensing decision, as the listing now
    does: cleared to publish under CC BY-NC-SA 4.0, every preset of both tools
    named, and no promise of m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
    [Measuring_Stencil.scad, Plug_Puller_Parametric.scad, Plug_Puller_SingleFile.scad]
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2026-10-01 Lengthen the one-sided body so a big finger keeps its full finger hole
    The auto-fit trims a finger hole wider than 40 % of the body's length or
    bottom width. A trim by the width raises the red tag FINGER TOO BIG FOR
    HAND WIDTH, but a trim by the length was silent, and with a short plug
    the fitted body was often too short: a 26 mm finger on an 85 mm hand got
    a 27.9 mm hole instead of 31.4 mm, and plain Large 27.06 mm instead of
    28.4 mm. The fitting step (fit_measured.scad and its Python mirror) now
    makes the body at least hole / 0.4 long (FIT_FINGER_HOLE_SHARE, D-11a),
    with an assert, and the auto-fit reads the same constant. On a grid of
    1,944 hands on the real model, silent trims went from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
    [Plug_Puller_Parametric.scad, Plug_Puller_SingleFile.scad, fit_measured.scad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]
2026-10-01 Stop naming development files a public reader cannot open
    Comments in the models and tests, the engineering reference and the
    medium fixture's description named development scripts (such as
    scripts/fit_body_outline.py and scripts/measure_plug_references.py), the
    v6.0 CAD files and a retired parity test, none of which are in this
    repository. They now say the work was done during development, and the
    presets comment names the tests that pin the Medium parity today. The
    scripts index no longer links the private plug-puller-openscad and
    cad-to-openscad-pipeline repositories, and a test comment no longer names
    the deleted measuring guide. Comments and text only: no shape changes.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
    [Plug_Puller_Parametric.scad, Plug_Puller_SingleFile.scad, Plug_Puller_Two_Sided.scad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]
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2026-10-02 Name one version, 0.14.0, everywhere the project states it
    The fixes since 0.13.0 are merged, so the CHANGELOG's unreleased block
    becomes 0.14.0 (dated 2026-10-01) and the places that state the version
    follow: the one-sided file's header, okh.yml, the README badge and
    MODEL_VERSION. Everything that prints the version is regenerated from it,
    as the 0.13.0 bump did: the flattened single file, the 21 outline sheets
    and their PDF, and both tools' quick starts and full guides (page counts
    15, 88, 13 and 54, unchanged). No geometry changed; three sheets also show
    the renderer's run-to-run jitter of hundredths of a millimeter.
    Claude-Session: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
    [Plug_Puller_Parametric.scad, Plug_Puller_SingleFile.scad]
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
